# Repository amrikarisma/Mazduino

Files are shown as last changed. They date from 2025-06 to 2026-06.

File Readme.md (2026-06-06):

# Mazduino
*Mazduino ECU* is built on **STM32** MCU, compatible with **rusEFI**-based firmware — including official **rusEFI**, **epicEFI**, **FomeEFI**, and other rusEFI-based custom firmware. For tuning and configuration, you can use the Tuner Studio software.

## Mazduino ECU Compact
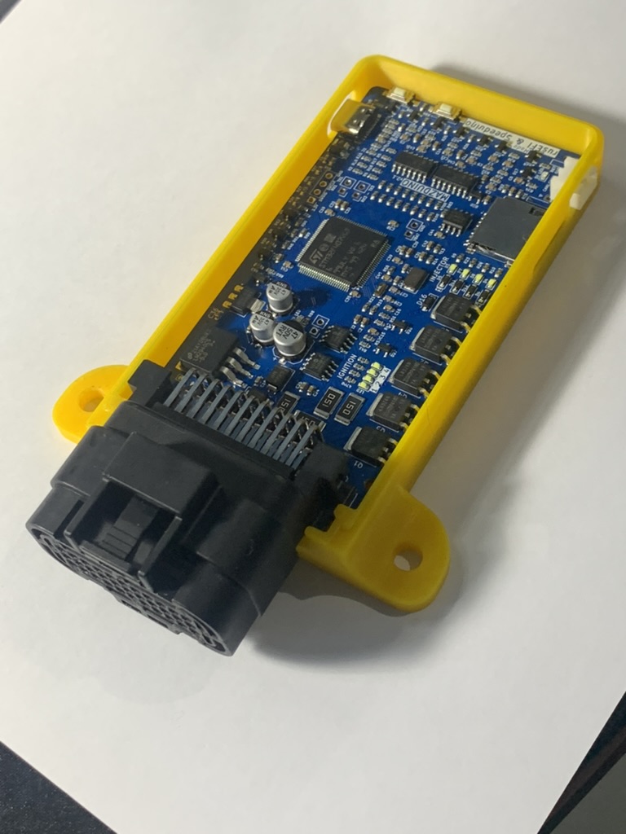
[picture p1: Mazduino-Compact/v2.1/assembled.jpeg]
Assembled Mazduino ECU

A compact and customizable Engine Control Unit (ECU) designed for **4-cylinder engines with full sequential injection and ignition**.

## Mazduino ECU Mini 6Ch
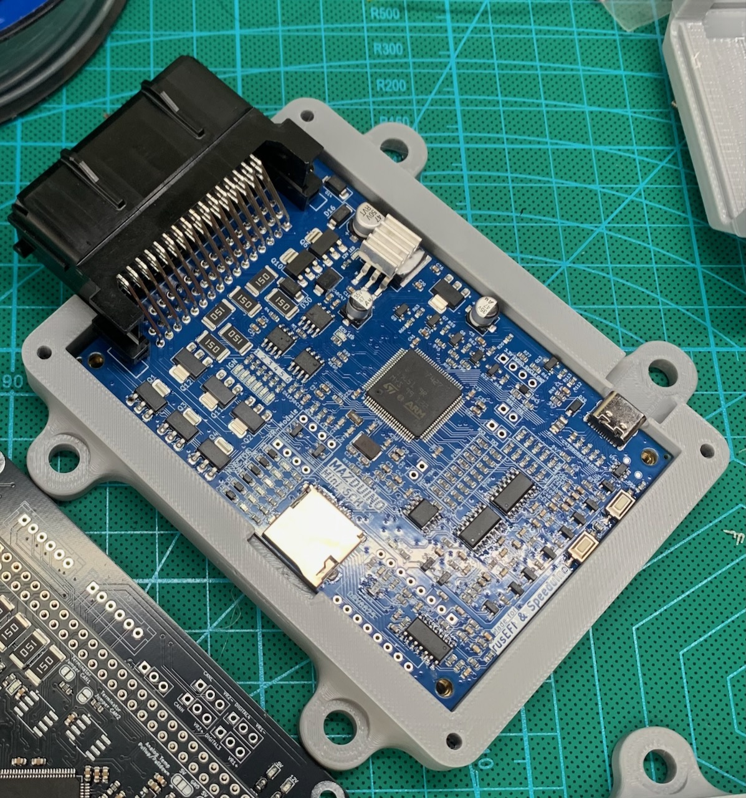
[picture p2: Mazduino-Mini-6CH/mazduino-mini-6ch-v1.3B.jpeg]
Assembled Mazduino ECU

A mini 6-channel version of the Mazduino ECU for **6-cylinder engines with full sequential injection and ignition**.

## Mazduino ECU Lite Edition
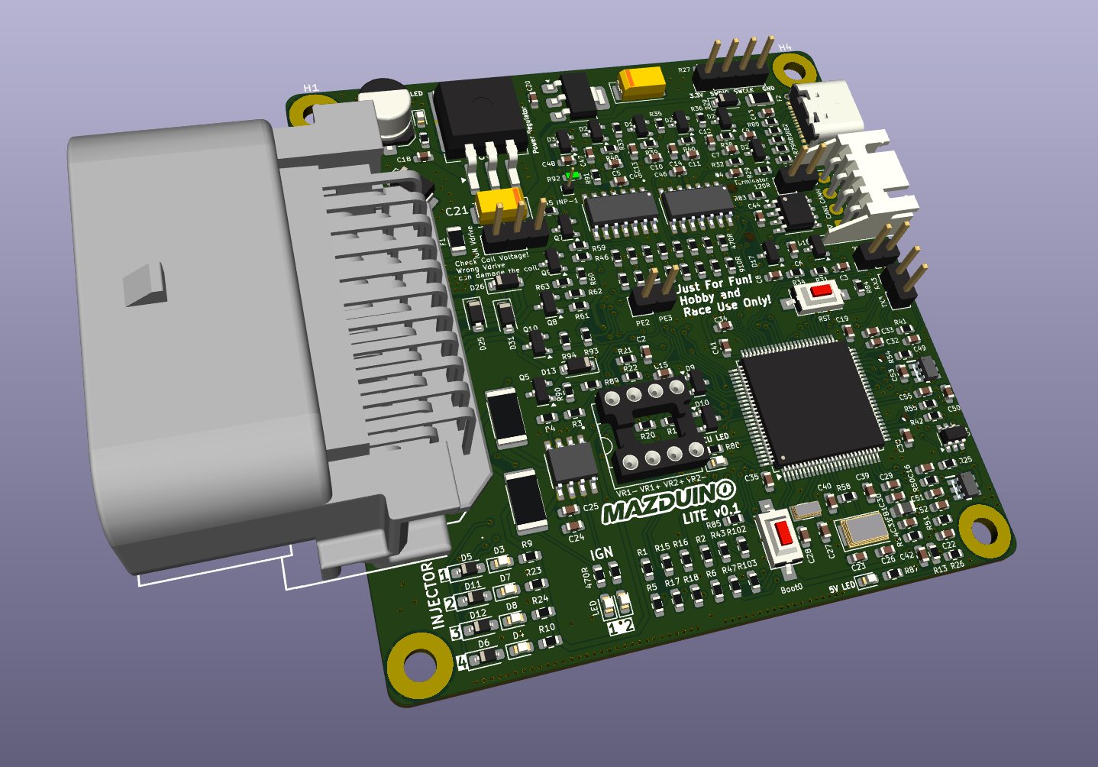
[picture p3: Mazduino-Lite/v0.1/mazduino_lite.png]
Mazduino Lite Edition

A lightweight and compact ECU designed for **4-cylinder engines with full sequential injection and wasted spark ignition**.

## Mazduino Display
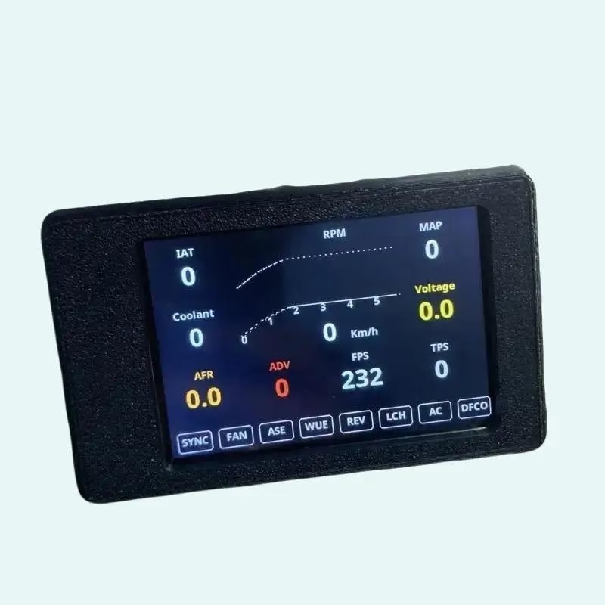
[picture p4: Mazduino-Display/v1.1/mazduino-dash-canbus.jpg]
Mazduino Display

A dedicated dashboard ECU display module that shows real-time vehicle data retrieved from the main ECU.

## Mazduino WBO (Wideband Oxygen Sensor Controller)
Mazduino WBO
A wideband oxygen sensor controller that communicates with the ECU via CAN bus for accurate air-fuel ratio monitoring. Supports LSU 4.2, LSU 4.9, and LSU 4.9 Adv sensors with easy manual assembly design.

*Documentation for all variants will be updated as soon as possible.*

## Links
### Mazduino
- **Official Website**: https://www.mazduino.com
- **Documentation & WIKI**: https://wiki.mazduino.com

### Firmware & Software
- **rusEFI**: https://rusefi.com/
- **Tuner Studio**: https://www.tunerstudio.com/index.php/tuner-studio

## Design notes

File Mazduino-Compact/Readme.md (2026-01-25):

# Mazduino Compact
Assembled Mazduino ECU

Mazduino Compact is compatible with firmware from rusEFI and can also be used with Speeduino.  
For tuning and configuration, you can use the Tuner Studio software.

## Downloads

### Latest Version (v2.3)
- [Download Schematic (PDF)](https://github.com/amrikarisma/Mazduino/blob/main/Mazduino-Compact/v2.3/schematic.pdf)
- [Interactive BOM v2.3](https://www.mazduino.com/ibom/compact-2-3-ibom.html)

### Other Versions
- [Interactive BOM v2.2](https://www.mazduino.com/ibom/compact-2-2-ibom.html)
- [Interactive BOM v2.0](https://www.mazduino.com/ibom/compact-2-0-ibom.html)
- [Interactive BOM v1.3](https://www.mazduino.com/ibom/compact-1-3-ibom.html)
*Interactive BOM for other versions will be available soon*

## Changelog

### v1.0
- Initial testing

### v1.1
- Fixed USB-C to USB-C connection: rerouted 5.1k resistor to CC1 & CC2  
- Corrected silkscreen typo  

### v1.2
- Added low-current output for main relay  
- Added spare analog input  
- Added jumper footprint  

### v2.0
- Replaced connector with a 33-pin Yamaha automotive connector  
- Changed 12V capacitor size from 5x5 to 6x5  

### v2.1
- Added one high-current low-side MOSFET for boost/VVT/Idle2 control  
- Added direct knock sensor support using an op-amp IC  
- Supported two types of CAN bus transceivers: MCP2551 or TJA1051T/3  
- Added a dedicated connector for CAN bus communication  
- Added a pin header footprint for VBAT, allowing real-time clock backup with a 3.3V battery

### v2.2
- Added high-side MOSFET for 12V switching control (alternator and other components requiring 12V switching)  

### v2.3
- Fixed MCU mapping for 12V battery input and knock sensor input  
- Optimized component selection and PCB layout for improved reliability and manufacturing efficiency  
- Added JST connector footprint for usb connector options  
- Added CR1220 battery holder footprint for real-time clock backup power

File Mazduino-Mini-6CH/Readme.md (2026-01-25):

# Mazduino Mini 6Ch

Mazduino Mini 6Ch is compatible with firmware from rusEFI and can also be used with Speeduino.  
For tuning and configuration, you can use the Tuner Studio software.

## Preview
<table>
  <tr>
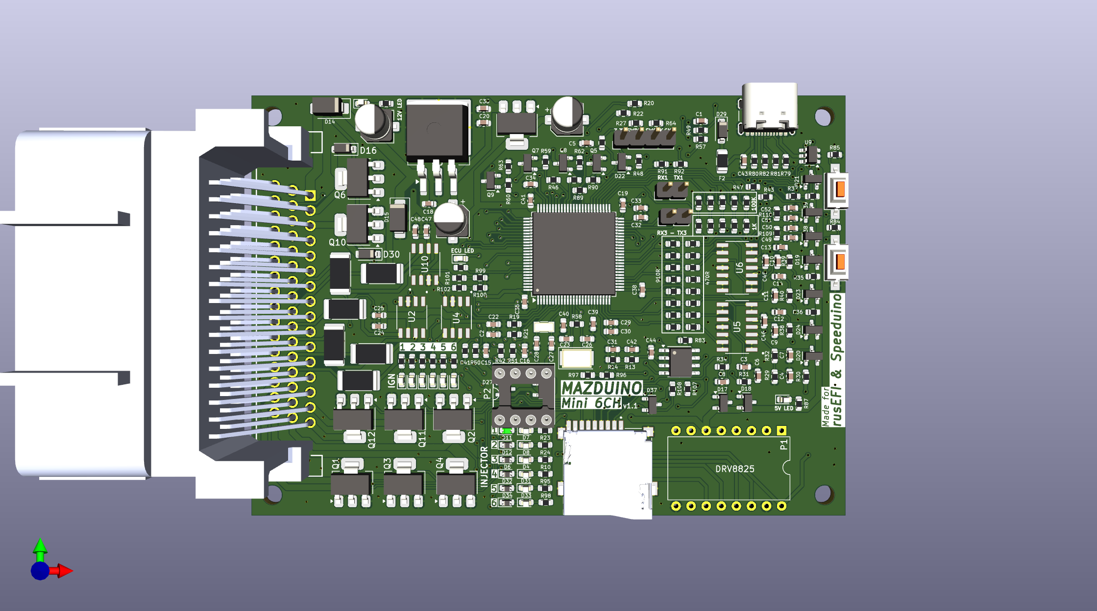
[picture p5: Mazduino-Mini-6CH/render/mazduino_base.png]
3D Render top
    <td></td>
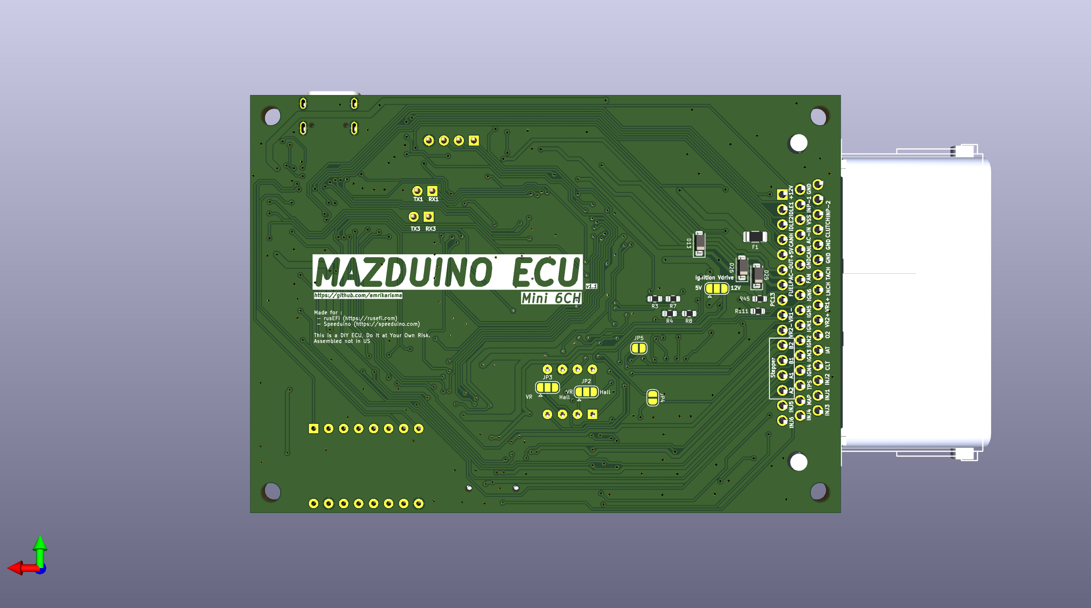
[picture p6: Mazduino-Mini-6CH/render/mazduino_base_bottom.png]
3D Render bottom
    <td></td>
  </tr>
  <tr>
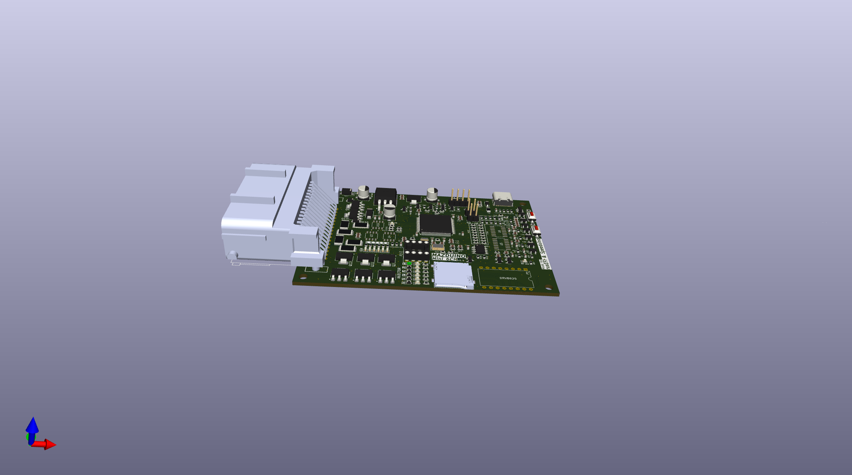
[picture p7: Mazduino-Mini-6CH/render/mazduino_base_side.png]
3D Render side
    <td></td>
    <td>Assembled Mazduino ECU</td>
  </tr>
</table>

## Features
- Processor/MCU: STM32F407
- 6 Channel Coil outputs for Smart Coil (For dumb coil, please add external IGBT)
- 6 Channel Injector outputs
- 2 High Current Outputs (Idle/Boost/VVT)
- Tachometer Output
- Fuel Pump Low Current Output
- FAN Low Current Output
- AC Compressor Low Current Output
- CKP Trigger Input (Hall/Optical/VR)
- CMP Trigger Input (Hall/Optical/VR)
- Supports VR-Conditioner Module (DIP 8)
- Supports Stepper Module (DRV8825)
- External MAP Sensor Analog Input
- TPS Sensor Analog Input
- IAT Sensor Analog Input
- ECT/CLT Sensor Analog Input
- O2 Sensor Analog Input
- Spare Analog Input 1 (Can be used for Fuel Pressure Sensor or others)
- Spare Analog Input 2 (Can be used for Oil Pressure Sensor or others)
- AC Switch Digital Input/GND signal
- Launch Control Input
- Clutch Input
- VSS Input
- Supports Micro SD Card for data logging via SPI
- Supports CANbus communication with MCP2551 IC
- Automotive 48-pin Yamaha ECU Connector

## Downloads

### Latest Version (v1.4)
- [Download Schematic (PDF)](https://github.com/amrikarisma/Mazduino/blob/main/Mazduino-Mini-6CH/v1.4/Schematics.pdf)
- [Interactive BOM v1.4](https://www.mazduino.com/ibom/mini6ch-1-4-ibom.html)

### Other Versions
- [Interactive BOM v1.3](https://www.mazduino.com/ibom/mini6ch-1-3-ibom.html)
- [Interactive BOM v1.2](https://www.mazduino.com/ibom/mini6ch-1-2-ibom.html)
  
## Changelog

### v1.0
- Initial Release

### v1.1
- Fix USB D+ and D-
- Add 2 Spare analog inputs
- Change AC Switch from Analog Input to Digital Pin (GND signal)

### v1.2
- Replace footprint Capacitor for Input Regulator 5V from 5x5 to 8x6
- Add low current output for Main relay control
- Fix DRV8825 schema for rusEFI

### v1.3
- Added ETB support
- Added Knock sensor support

### v1.4 (latest)
- Added spare inputs to support TPS1, TPS2, PPS1, PPS2
- Added support for ETB1 and ETB2
- Motor driver uses 2x TLE9201SG ICs (can be used for Idle Stepper Motor when not used for ETB)
- Removed DRV8825 module support

---

*This documentation will be updated as soon as possible... please wait.*

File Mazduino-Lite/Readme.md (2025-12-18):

# Mazduino Lite Edition

Mazduino Lite Edition is a compact ECU designed for **4-cylinder engines with wasted spark ignition or 1-2 cylinder motorcycles with individual ignition control**. All configurations support full sequential injection. This lightweight version provides essential engine control features in a smaller form factor.

Mazduino Lite is compatible with firmware from rusEFI and can also be used with Speeduino.  
For tuning and configuration, you can use the Tuner Studio software.

## Specifications
- **Board Size**: 72mm x 74.7mm
- **Connector**: 33-pin Automotive Connector
- **Target Application**: 
  - 4-cylinder engines with full sequential injection and wasted spark ignition
  - 1-cylinder motorcycles with sequential injection and individual ignition control
  - 2-cylinder motorcycles with sequential injection and individual ignition control (Smart Coil/IGBT)

## Preview
### v0.1
<table>
  <tr>
    <td>Mazduino Lite v0.1</td>
    <td></td>
  </tr>
</table>

### v0.2
<table>
  <tr>
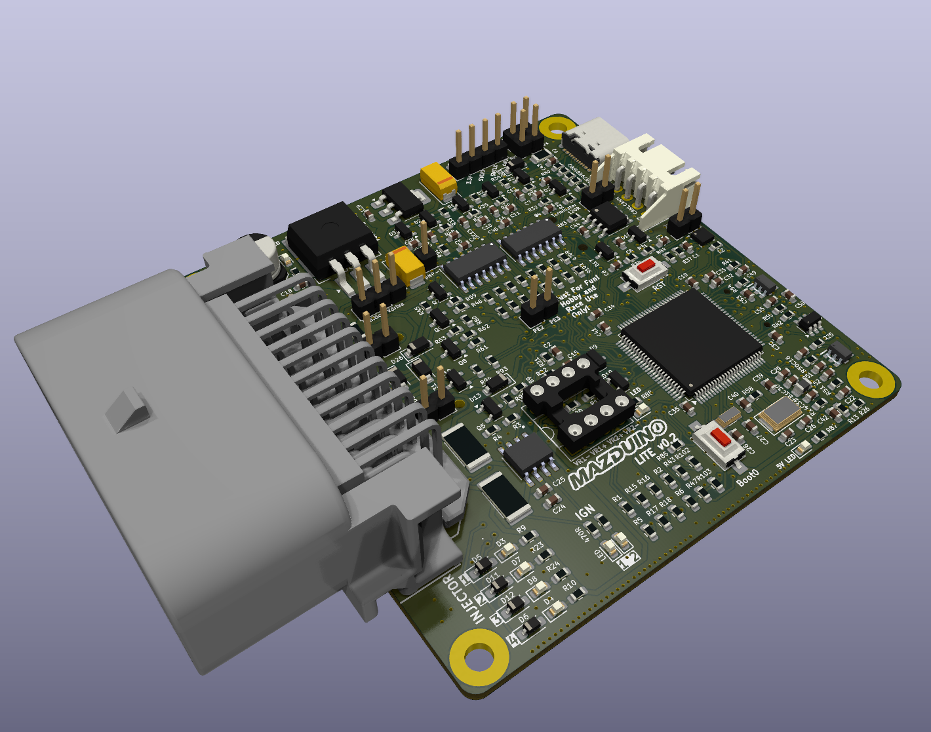
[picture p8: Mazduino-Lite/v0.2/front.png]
Mazduino Lite v0.2 Top
    <td></td>
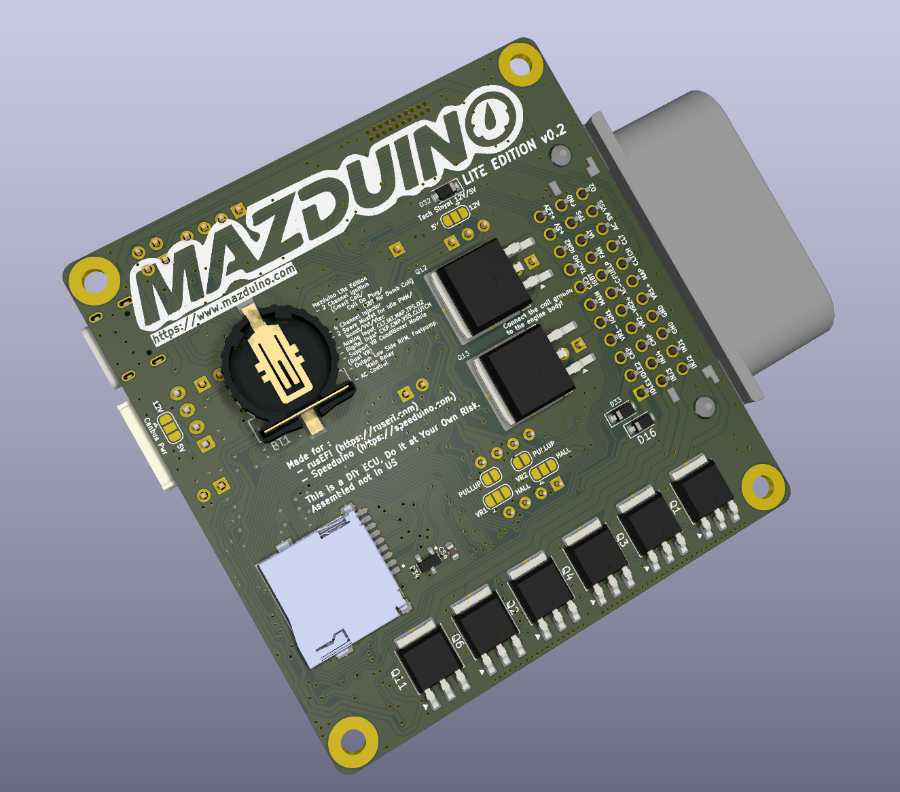
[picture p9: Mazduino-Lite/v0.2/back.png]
Mazduino Lite v0.2 Bottom
    <td></td>
  </tr>
</table>

## Features
- **Processor/MCU**: STM32F407
- **2 Channel Ignition** - Wasted Spark (Smart Coil/Coil On Plug/IGBT for Dumb Coil)
- **4 Channel Injector** outputs - Full Sequential Injection
- **2 Spare MOSFET** for Idle PWM/Boost/VVT/VTEC control
- **Analog Inputs**: CLT, IAT, MAP, TPS, O2 sensors
- **Internal Baro Pressure Sensor**: Built-in barometric pressure sensor (v0.2+)
- **Digital Inputs**: CKP, CMP, VSS, Clutch
- **VR Conditioner Module Support** (Dual VR)
- **Low Side Outputs**: RPM, FAN, Fuel Pump, Main Relay, AC Compressor
- **Micro SD Card Support** for data logging via SPI
- **CANbus Communication** support
- **Compact Design** - Smaller footprint for space-constrained applications

## Downloads

### Latest Version (v0.2)
- [Download Schematic (PDF)](https://github.com/amrikarisma/Mazduino/blob/main/Mazduino-Lite/v0.2/Schematics.pdf)
- [Interactive BOM v0.2](https://www.mazduino.com/ibom/lite-0-2-ibom.html)

### Other Versions
- [Download Schematic v0.1 (PDF)](https://github.com/amrikarisma/Mazduino/blob/main/Mazduino-Lite/v0.1/Schematics.pdf)
- [Interactive BOM v0.1](https://www.mazduino.com/ibom/lite-0-1-ibom.html)

## Changelog

### v0.2 (Latest - Important IGBT Revision)
- **Critical IGBT Fix**: Resolved design error in v0.1 that could prevent IGBT functionality
- **Footprint Change**: Updated IGBT footprint from Dpak 252 to d2pak 262 (commonly used for IGBT)
- **Added Internal Baro Pressure Sensor**: Built-in barometric pressure sensor for improved engine management
- Design validation and schematic corrections

### v0.1 (Initial Release)
- Initial design and layout
- Compact 72mm x 74.7mm form factor
- 33-pin automotive connector
- 4-cylinder full sequential injection with wasted spark ignition
- 2-channel ignition and 4-channel injection
- Essential analog and digital inputs
- VR conditioner support
- CAN bus and SD card support
- ⚠️ **Note**: Contains IGBT design issue for dumb coils (resolved in v0.2)
- ✅ **Still usable**: Works perfectly with Coil on Plug (CoP) or Smart Coil configurations

---

*This documentation will be updated as soon as possible... please wait.*

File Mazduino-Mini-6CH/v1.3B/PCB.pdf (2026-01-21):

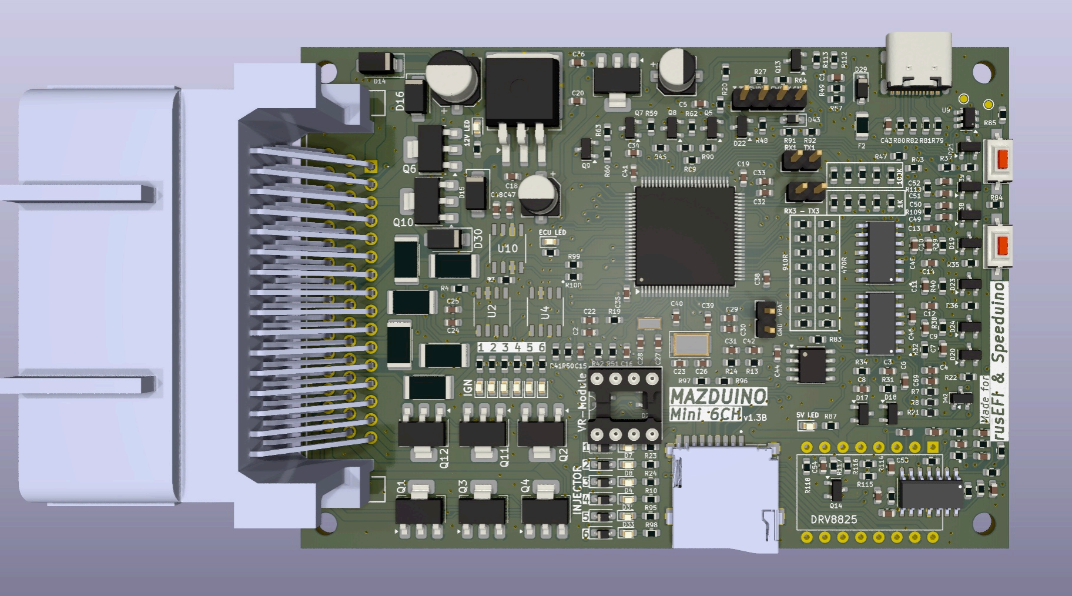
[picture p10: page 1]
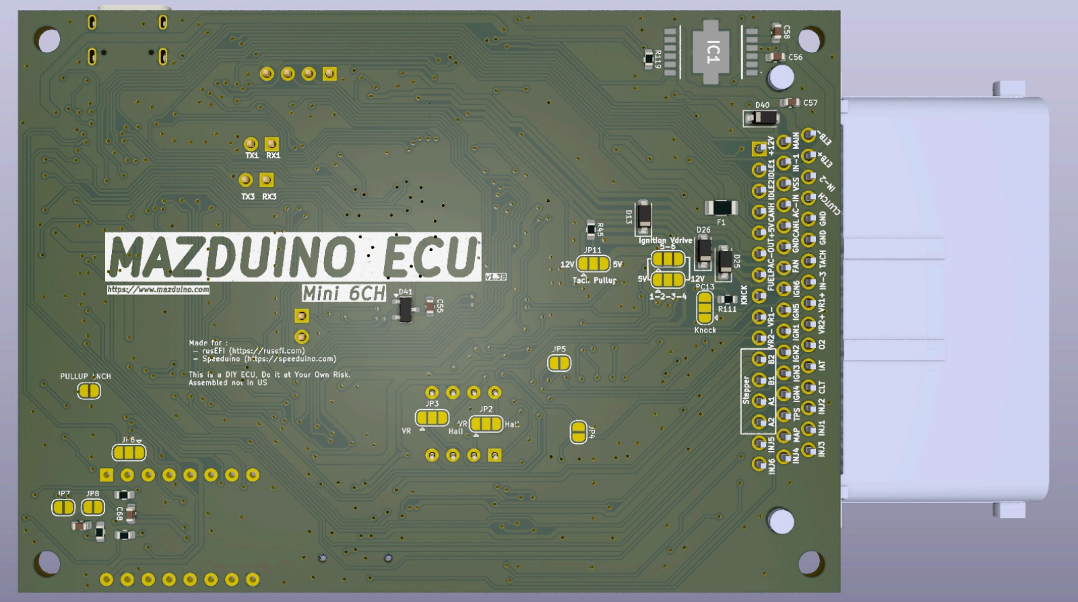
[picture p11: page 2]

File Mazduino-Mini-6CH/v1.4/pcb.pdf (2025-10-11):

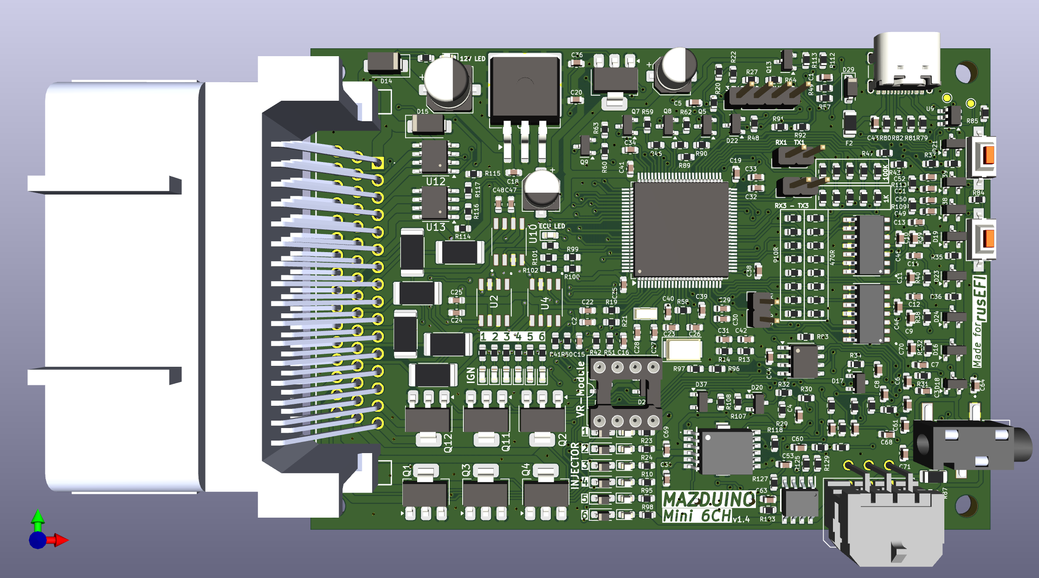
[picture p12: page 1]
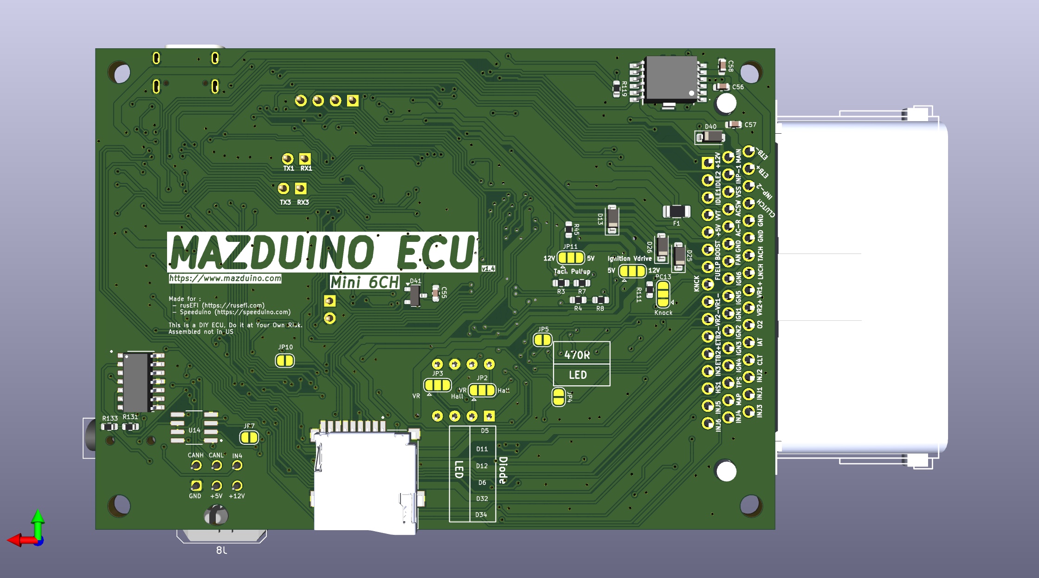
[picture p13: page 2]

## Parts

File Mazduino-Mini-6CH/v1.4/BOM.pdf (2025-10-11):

Reference | Value | Footprint | Qty
C1,C2,C3,C7,C9,C10,C11,C16,C18,C19,C20,C24,C30,C35,C36,C38,C39,C40,C41,C42,C44,C45,C46,C47,C49,C51,C55,C61,C64,C68 100nF | | Capacitor_SMD:C_0603_1608Metric | 30
C4,C22,C25,C29,C31,C33,C48 | 1uF | Capacitor_SMD:C_0603_1608Metric | 7
C5,C6,C12,C13,C14,C50,C52,C70 | 220nF | Capacitor_SMD:C_0603_1608Metric | 8
C8 | 470pF | Capacitor_SMD:C_0603_1608Metric | 1
C15,C53,C54,C57,C58,C59,C63 | 10nF | Capacitor_SMD:C_0603_1608Metric | 7
C17 | 10uF | Capacitor_SMD:CP_Elec_6.3x5.4 | 1
C21 | 47uF | Capacitor_SMD:CP_Elec_5x5.3 | 1
C23,C26 | 12pF | Capacitor_SMD:C_0603_1608Metric | 2
C27,C28 | 20pF | Capacitor_SMD:C_0603_1608Metric | 2
C32,C34 | 2.2uF | Capacitor_SMD:C_0603_1608Metric | 2
C37 | 47uF | Capacitor_SMD:CP_Elec_5x5.4 | 1
C43,C56,C69,C71 | 10uF | Capacitor_SMD:C_0603_1608Metric | 4
C60 | 3.3nF | Capacitor_SMD:C_0603_1608Metric | 1
C62 | 680pF | Capacitor_SMD:C_0603_1608Metric | 1
C65 | 330pF | Capacitor_SMD:C_0603_1608Metric | 1
C66 | 47pF | Capacitor_SMD:C_0603_1608Metric | 1
D1,D2,D3,D4,D7,D8,D9,D10,D31,D33,D35,D36 | LED | LED_SMD:LED_0603_1608Metric | 12
D5,D6,D11,D12,D32,D34 | 1N4148WS | Diode_SMD:D_SOD-323_HandSoldering | 6
D13,D25,D26,D29,D40 | 1N5819W | Diode_SMD:D_SOD-123 | 5
D14 | SS14 | Diode_SMD:D_SMA | 1
D15 | D_TVS | Diode_SMD:D_SMA | 1
D16,D17,D18,D19,D20,D21,D22,D23,D24,D27,D28,D37,D38,D39 | BAT54S | Package_TO_SOT_SMD:SOT-23 | 14
D41 | BAT54C | Package_TO_SOT_SMD:SOT-23 | 1
F1,F3 | 0.5A | Fuse:Fuse_1206_3216Metric | 2
F2 | 1206 | Fuse:Fuse_1206_3216Metric | 1
IC1,IC2 | TLE9201SG | TLE9201SG | 2
IC3 | BTS4175SGA | SOIC127P600X175-8N | 1
J1,J6,J7 | Conn_01x02 | Connector_PinHeader_2.54mm:PinHeader_1x02_P2.54mm_Vertical | 3
J2 | STLink | Connector_PinHeader_2.54mm:PinHeader_1x04_P2.54mm_Vertical | 1
J3 | USB_C_Receptacle_USB2.0 | Connector_USB:USB_C_Receptacle_GCT_USB4105-xx-A_16P_TopMnt_Horizontal | 1
J4 | PJ-320B | PJ-320B:BOOMELE_PJ-320B | 1
J5 | MSD-1-A | MSD_1_A:CUI_MSD-1-A | 1
J8 | Conn_02x02_Top_Bottom | Connector_Molex:Molex_Micro-Fit_3.0_43045-0600_2x03_P3.00mm_Horizontal | 1
J9 | S48B-ZROK-2A-R | S48BZROK2AR | 1
JP1 | Ignition Voltage | Jumper:SolderJumper-3_P1.3mm_Open_RoundedPad1.0x1.5mm | 1
JP2,JP3 | HALL_VR | Jumper:SolderJumper-3_P1.3mm_Open_RoundedPad1.0x1.5mm | 2
JP4,JP5 | PULLUP | Jumper:SolderJumper-2_P1.3mm_Open_RoundedPad1.0x1.5mm | 2
JP10 | VRef | Jumper:SolderJumper-2_P1.3mm_Open_RoundedPad1.0x1.5mm | 1
LED1,LED2,LED3 | RED | LED_SMD:LED_0603_1608Metric | 3
P2 | Dual VR C | Package_DIP:DIP-8_W7.62mm_Socket | 1
Q1,Q2,Q3,Q4,Q11,Q12 | Q_NMOS_GDS | Package_TO_SOT_SMD:SOT-223-3_TabPin2 | 6
Q5,Q7,Q8,Q9,Q13 | AO3400A | Package_TO_SOT_SMD:SOT-23 | 5
R1,R2,R15,R16,R43,R91,R93,R96,R114,R115 | 100k | Resistor_SMD:R_0603_1608Metric | 10
R3,R4,R19,R20,R27,R29,R33,R45,R59,R62,R63,R64,R84,R85,R90,R99,R100,R113,R118,R119,R125,R127,R129 10K | | Resistor_SMD:R_0603_1608Metric | 23
R5,R6,R17,R18,R37,R47,R49,R92,R94,R97,R107,R116,R117 | 1k | Resistor_SMD:R_0603_1608Metric | 13
R7,R8,R21,R22,R101,R102 | 0R | Resistor_SMD:R_0603_1608Metric | 6
R9,R10,R23,R24,R95,R98 | 2.4k | Resistor_SMD:R_0603_1608Metric | 6
R11,R12,R13,R25,R26,R28,R31,R32,R34,R38,R39,R40,R44,R48,R50,R51,R65,R66,R71,R72,R73,R74,R87,R88,R103,R104,R109,R110,R131,R132 470R | | Resistor_SMD:R_0603_1608Metric | 30
R14,R67,R68,R69,R70,R75,R76,R77,R78,R133 | 910R | Resistor_SMD:R_0603_1608Metric | 10
R30 | 82K | Resistor_SMD:R_0603_1608Metric | 1
R35,R36 | 2.49k | Resistor_SMD:R_0603_1608Metric | 2
R41,R42,R56,R86,R108 | 2k7 | Resistor_SMD:R_0603_1608Metric | 5
R46,R60,R61,R89,R112 | 100R | Resistor_SMD:R_0603_1608Metric | 5
R52,R53,R54,R55,R105,R106 | 15R | Resistor_SMD:R_2512_6332Metric | 6
R57 | 220R | Resistor_SMD:R_0603_1608Metric | 1
R58 | 1M | Resistor_SMD:R_0603_1608Metric | 1
R79,R80 | 5.1K | Resistor_SMD:R_0603_1608Metric | 2
R81,R82,R111 | 22R | Resistor_SMD:R_0603_1608Metric | 3
R83,R123 | 4.7K | Resistor_SMD:R_0603_1608Metric | 2
R120,R121,R130 | 33K | Resistor_SMD:R_0603_1608Metric | 3
R122,R128 | 100K | Resistor_SMD:R_0603_1608Metric | 2
R124 | 470K | Resistor_SMD:R_0603_1608Metric | 1
R126 | 12K | Resistor_SMD:R_0603_1608Metric | 1
R134,R136 | 470R | Resistor_SMD:R_0603_1608Metric | 2
R135,R137 | 910R | Resistor_SMD:R_0603_1608Metric | 2
SW1,SW2 | SW_Push | Button_Switch_SMD:SW_SPST_CK_RS282G05A3 | 2
TP1,TP2 | TestPoint | TestPoint:TestPoint_Pad_D1.0mm | 2
U1 | STM32F407VGTx | Package_QFP:LQFP-100_14x14mm_P0.5mm | 1
U2,U4,U10 | TC4424A | TC4424AVOA:SOIC127P599X175-8N | 3
U3 | AMS1117-3.3 | Package_TO_SOT_SMD:SOT-223-3_TabPin2 | 1
U5,U6,U11 | MCP6004 | MCP6004T_I_SL:SOIC127P600X175-14N | 3
U7 | MCP2551-I-SN | Package_SO:SOIC-8_3.9x4.9mm_P1.27mm | 1
U8 | LM2940S-5.0 | Package_TO_SOT_SMD:TO-263-3_TabPin2 | 1
U9 | USBLC6-2SC6 | Package_TO_SOT_SMD:SOT-23-6 | 1
U12,U13 | VNLD5090 | Package_SO:SO-8_3.9x4.9mm_P1.27mm | 2
U14 | MCP6002-xSN | MCP6002T_I_SN:SOIC127P600X175-8N | 1
Y1 | 8Mhz | Crystal:Crystal_SMD_5032-2Pin_5.0x3.2mm | 1
Y2 | 32.768KHz | Crystal:Crystal_SMD_3215-2Pin_3.2x1.5mm | 1

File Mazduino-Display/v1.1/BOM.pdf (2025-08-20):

## BOM Mazduino Display Canbus www.mazduino.com

Qty | Reference | Value | Footprint
2 | C1,C13 | 220uF | Capacitor_SMD:C_Elec_8x10.2
1 | C2 | 100nF | Capacitor_SMD:C_0805_2012Metric
2 | C3,C12 | 22uF | Capacitor_SMD:CP_Elec_5x5.4
5 | C4,C6,C8,C10,C11 | 0.1uF/100nF | Capacitor_SMD:C_0805_2012Metric
2 | C5,C7 | 22uF | Capacitor_SMD:C_0805_2012Metric
1 | C9 | 100nF | Capacitor_SMD:C_0603_1608Metric
1 | D2 | SS14 | Diode_SMD:D_SMA
1 | D3 | SP0503BAHT | Package_TO_SOT_SMD:SOT-143
2 | D4,D5 | SS36 | Diode_SMD:D_SMA
1 | J1 | Conn_01x02_Pin | Connector_JST:JST_XH_B2B-XH-A_1x02_P2.50mm_Vertical
1 | J2 | JST 4P | Connector_JST:JST_XH_B4B-XH-A_1x04_P2.50mm_Vertical
1 | J3 | TFT SPI | Connector_PinSocket_2.54mm:PinSocket_1x14_P2.54mm_Vertical
1 | J5 | USB_C_Receptacle_USB2.0 | Connector_USB:USB_C_Receptacle_GCT_USB4105-xx-A_16P_TopMnt_Horizontal
2 | J6,J7 | TFT SD | Connector_PinSocket_2.54mm:PinSocket_1x04_P2.54mm_Vertical
1 | JP1 | Jumper_2_Open | Connector_PinHeader_2.54mm:PinHeader_1x02_P2.54mm_Vertical
1 | L1 | 33uH | Inductor_SMD:L_10.4x10.4_H4.8
2 | LED1,LED4 | LED | LED_SMD:LED_0805_2012Metric
1 | LED2 | BLUE | LED_SMD:LED_0805_2012Metric
1 | LED3 | GREEN | LED_SMD:LED_0805_2012Metric
2 | Q1,Q2 | SS8050 | Package_TO_SOT_SMD:SOT-23
4 | R1,R6,R9,R10 | 10K | Resistor_SMD:R_0805_2012Metric
1 | R2 | 22.1K | Resistor_SMD:R_0805_2012Metric
3 | R3,R17,R18 | 470R | Resistor_SMD:R_0805_2012Metric
1 | R4 | 47.5K | Resistor_SMD:R_0805_2012Metric
1 | R5 | 2K | Resistor_SMD:R_0805_2012Metric
2 | R7,R8 | 0R | Resistor_SMD:R_0805_2012Metric
1 | R11 | 4.7K | Resistor_SMD:R_0603_1608Metric
2 | R12,R13 | 5k1 | Resistor_SMD:R_0805_2012Metric
1 | R14 | 120R | Resistor_SMD:R_0805_2012Metric
2 | R15,R16 | 100R | Resistor_SMD:R_0805_2012Metric
1 | R19 | 4.7K | Resistor_SMD:R_0805_2012Metric
2 | SW1,SW2 | SW_Push | Button_Switch_THT:SW_PUSH_6mm
1 | U1 | AMS1117-3.3 | Package_TO_SOT_SMD:SOT-223-3_TabPin2
1 | U3 | ESP32-WROOM-32D | RF_Module:ESP32-WROOM-32D
1 | U4 | CP2102N-Axx-xQFN28 | Package_DFN_QFN:QFN-28-1EP_5x5mm_P0.5mm_EP3.35x3.35mm
1 | U5 | MCP2551-I-SN | Package_SO:SOIC-8_3.9x4.9mm_P1.27mm
1 | U6 | ESP32-DevKitC | PCM_Espressif:ESP32-DevKitC
1 | U7 | LM2596S-5 | Package_TO_SOT_SMD:TO-263-5_TabPin3

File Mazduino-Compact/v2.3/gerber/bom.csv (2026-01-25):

Designator | Footprint | Quantity | Value | LCSC Part #
BT1 | CR1220-2 | 1 | Battery_Cell
C1, C10, C11, C18, C2, C24, C3, C30, C36, C4, C42, C43, C44, C45, C46, C47, C54, C56, C9 | 0603 | 19 | 100nF
C12 | 0603 | 1 | 220nF | C21120
C13, C14, C48, C5, C6, C7 | 0603 | 6 | 220nF
C15, C19, C35, C38, C39, C40, C41 | 0603 | 7 | 100nF | C14663
C16, C53, C55 | 0603 | 3 | 10nF
C17 | CP_Elec_6.3x5.4 | 1 | 10uF
C21 | CP_Elec_5x5.3 | 1 | 47uF
C22 | 0603 | 1 | 1uF | C15849
C23 | 0603 | 1 | 12pF | C38523
C25, C29, C31, C33, C57 | 0603 | 5 | 1uF
C26 | 0603 | 1 | 12pF
C27 | 0603 | 1 | 20pF | C1648
C28 | 0603 | 1 | 20pF
C32 | 0603 | 1 | 2.2uF | C23630
C34 | 0603 | 1 | 2.2uF
C37 | CP_Elec_5x5.4 | 1 | 47uF
C49 | 0603 | 1 | 3.3nF
C50 | 0603 | 1 | 680pF
C51 | 0603 | 1 | 330pF
C52 | 0603 | 1 | 47pF
C8 | 0603 | 1 | 470pF | C1620
D1, D2, D3, D4, D7, D8, D9 | 0603 | 7 | LED
D10 | 0603 | 1 | LED | C2290
D11 | D_SOD-323_HandSoldering | 1 | 1N4148WS | C2128
D12, D5, D6 | D_SOD-323_HandSoldering | 3 | 1N4148WS
D13, D16, D25, D26, D29, D31, D32, D33 | D_SOD-123 | 8 | 1N5819W
D14 | D_SMA | 1 | SS14 | C2480
D15 | D_SMA | 1 | SMBJ40A
D17 | SOT-23 | 1 | BAT54S | C7420333
D18, D19, D20, D21, D22, D23, D24, D27, D28, D30, D35 | SOT-23 | 11 | BAT54S
D34 | SOT-23 | 1 | BAT54C
F1 | 1206 | 1 | 0.5A
F2 | 1206 | 1 | 1206
IC1 | SOIC127P600X175-8N | 1 | BTS4175SGA
J1 | JST_XH_S4B-XH-A-1_1x04_P2.50mm_Horizontal | 1 | Conn_01x04
J10 | JST_GH_SM04B-GHS-TB_1x04-1MP_P1.25mm_Horizontal | 1 | Conn_01x04
J2 | PinHeader_1x04_P2.54mm_Vertical | 1 | STLink
J3 | USB_C_Receptacle_GCT_USB4105-xx-A_16P_TopMnt_Horizontal | 1 | TYPE-C 16PIN 2MD(073) | C2765186
J4 | PinHeader_1x01_P2.54mm_Vertical | 1 | Conn_01x01
J5 | CUI_MSD-1-A | 1 | THD2528-11SD-GF
J6, J7, J8 | PinHeader_1x02_P2.54mm_Vertical | 3 | Conn_01x02
J9 | 15544582 | 1 | 1554458-2
JP1 | SolderJumper-3_P1.3mm_Open_RoundedPad1.0x1.5mm | 1 | Ignition Voltage
LED1 | 0603 | 1 | RED | C2286
LED2, LED3, LED4 | 0603 | 3 | RED | SML-310LTT86
Q1, Q11, Q2, Q3, Q4, Q6 | TO-252-3_TabPin2 | 6 | Q_NMOS_GDS
Q10, Q7, Q8, Q9 | SOT-23 | 4 | AO3400A | C344010
Q5 | SOT-23 | 1 | AO3400A | C20917
R1, R102, R16, R2, R43, R95, R98 | 0603 | 7 | 100k
R10 | 0603 | 1 | 2.4k | C22940
R100, R101, R99 | 0603 | 3 | 33K
R103, R18, R37, R47, R49, R5, R6 | 0603 | 7 | 1k
R104 | 0603 | 1 | 4.7K
R105, R106, R107, R108, R19, R20, R27, R3, R4, R64, R84, R85 | 0603 | 12 | 10K
R109 | 0603 | 1 | 82K
R11, R12, R25, R26, R30, R34, R38, R39, R40, R48, R51, R92 | 0603 | 12 | 470r
R13, R28, R44, R65, R66, R71, R72, R73, R74 | 0603 | 9 | 470
R14 | 0603 | 1 | 910 | C140066
R15 | 0603 | 1 | 100k | C25803
R17 | 0603 | 1 | 1k | C21190
R23, R24, R9 | 0603 | 3 | 2.4k
R29, R35, R36, R91 | 0603 | 4 | 2.49k
R31 | 0603 | 1 | 470R | C23179
R33, R59, R62, R63, R90, R94 | 0603 | 6 | 10k | C25804
R41, R42, R56 | 0603 | 3 | 2k7
R45 | 0603 | 1 | 10k | C21190
R46, R60, R61, R89, R93 | 0603 | 5 | 100R | C22775
R50 | 0603 | 1 | 470R | C22962
R52, R53, R54, R55 | 2512 | 4 | 15R
R57 | 0603 | 1 | 220R
R58 | 0603 | 1 | 1M | C22935
R67, R68, R69, R70, R75, R76, R77, R78 | 0603 | 8 | 910
R7, R87, R88 | 0603 | 3 | 470r | RK73H2ATTD4700F
R79 | 0603 | 1 | 5.1K | C23186
R80 | 0603 | 1 | 5.1K
R81 | 0603 | 1 | 22R | C23345
R82 | 0603 | 1 | 22R
R83 | 0603 | 1 | 4.7K | C23162
R86 | 0603 | 1 | 2k7 | C13167
R96 | 0603 | 1 | 470K
R97 | 0603 | 1 | 12K
SW1 | SW_SPST_CK_RS282G05A3 | 1 | SW_Push | TSA363G25-250B
SW2 | SW_SPST_CK_RS282G05A3 | 1 | SW_Push
U1 | LQFP-100_14x14mm_P0.5mm | 1 | STM32F407VGTx | C12345
U10 | SOIC127P600X175-8N | 1 | MCP6002-xSN
U2, U4 | SOIC127P599X175-8N | 2 | TC4424AVOA | C44150
U3 | SOT-223-3_TabPin2 | 1 | AMS1117-3.3 | C6186
U5, U6 | SOIC127P600X175-14N | 2 | MCP6004
U7 | SOIC-8_3.9x4.9mm_P1.27mm | 1 | MCP2551-I-SN
U8 | TO-263-3_TabPin2 | 1 | LM2940S-5.0
Y1 | Crystal_SMD_5032-2Pin_5.0x3.2mm | 1 | 8Mhz | C115962
Y2 | Crystal_SMD_3215-2Pin_3.2x1.5mm | 1 | 32.768KHz | C32346

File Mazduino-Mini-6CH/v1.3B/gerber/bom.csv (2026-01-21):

Designator | Footprint | Quantity | Value | LCSC Part #
C1, C10, C11, C16, C18, C2, C20, C24, C3, C30, C36, C4, C42, C44, C45, C46, C47, C49, C51, C55, C68, C9 | 0603 | 22 | 100nF
C12, C13, C14, C5, C50, C52, C6, C7 | 0603 | 8 | 220nF
C15, C57, C58, C59 | 0603 | 4 | 10nF
C17 | CP_Elec_6.3x5.4 | 1 | 10uF
C19, C35, C38, C39, C40, C41 | 0603 | 6 | 100nF | C14663
C21 | CP_Elec_5x5.3 | 1 | 47uF
C22, C25, C29, C31, C33, C48, C69 | 0603 | 7 | 1uF
C23, C26 | 0603 | 2 | 18pF | C1647
C27, C28 | 0603 | 2 | 6.8pF | C1679
C32, C34, C53 | 0603 | 3 | 2.2uF
C37 | CP_Elec_5x5.4 | 1 | 47uF
C43, C56 | 0603 | 2 | 10uF
C54 | 0603 | 1 | 22nF
C60, C61 | 0603 | 2 | 3.3nF
C62, C63 | 0603 | 2 | 680pF
C64, C65 | 0603 | 2 | 330pF
C66, C67 | 0603 | 2 | 47pF
C8 | 0603 | 1 | 470pF
D1, D10, D2, D3, D31, D33, D35, D36, D4, D7, D8, D9 | 0603 | 12 | LED
D11, D12, D32, D34, D43, D5, D6 | D_SOD-323_HandSoldering | 7 | 1N4148WS
D13, D25, D26, D29, D40 | D_SOD-123 | 5 | 1N5819W
D14, D16, D30 | D_SMA | 3 | SS14 | C2480
D15 | D_SMA | 1 | D_TVS
D17, D18, D19, D20, D21, D22, D23, D24, D27, D28, D38, D39, D42 | SOT-23 | 13 | BAT54S
D41 | SOT-23 | 1 | BAT54C
F1 | 1206 | 1 | 0.5A
F2 | 1206 | 1 | 1206 | C163133
IC1 | TLE9201SG | 1 | TLE9201SG
J1, J6, J7 | PinHeader_1x02_P2.54mm_Vertical | 3 | Conn_01x02
J2 | PinHeader_1x04_P2.54mm_Vertical | 1 | STLink
J3 | USB_C_Receptacle_GCT_USB4105-xx-A_16P_TopMnt_Horizontal | 1 | USB_C_Receptacle_USB2.0 | C2765186
J5 | CUI_MSD-1-A | 1 | MSD-1-A
J9 | S48BZROK2AR | 1 | S48B-ZROK-2A-R
JP1, JP12 | SolderJumper-3_P1.3mm_Open_RoundedPad1.0x1.5mm | 2 | Ignition Voltage
JP10, JP4, JP5 | SolderJumper-2_P1.3mm_Open_RoundedPad1.0x1.5mm | 3 | PULLUP | DNP
JP2, JP3 | SolderJumper-3_P1.3mm_Open_RoundedPad1.0x1.5mm | 2 | HALL_VR | DNP
LED1, LED2, LED3 | 0603 | 3 | RED | SML-310LTT86
P1 | DRV8825 | 1 | DRV8825
P2 | DIP-8_W7.62mm_Socket | 1 | Dual VR C | DNP
Q1, Q11, Q12, Q2, Q3, Q4 | SOT-223-3_TabPin2 | 6 | Q_NMOS_GDS
Q10, Q6 | SOT-223-3_TabPin2 | 2 | BSP78
Q13, Q5, Q7, Q8, Q9 | SOT-23 | 5 | AO3400A | C344010
Q14 | SOT-23 | 1 | BC817
R1, R122, R123, R128, R129, R15, R16, R2, R43, R91, R93, R96 | 0603 | 12 | 100k
R10, R23, R24, R9, R95, R98 | 0603 | 6 | 2.4k
R100, R19, R20, R27, R3, R33, R4, R64, R7, R84, R85, R99 | 0603 | 12 | 10K
R103, R104, R109, R11, R110, R12, R13, R25, R26, R28, R31, R32, R34, R38, R39, R40, R44, R48, R50, R51, R65, R66, R71, R72, R73, R74 | 0603 | 26 | 470R
R105, R106, R52, R53, R54, R55 | 2512 | 6 | 15R
R111, R81, R82 | 0603 | 3 | 22R
R112, R46, R60, R61, R89 | 0603 | 5 | 100R | C22775
R113, R117, R118, R119, R59, R62, R63, R90 | 0603 | 8 | 10K | C25804
R114, R116 | 0603 | 2 | 68K | C25804
R115 | 0603 | 1 | 5.1R | C25804
R120, R121, R130, R131 | 0603 | 4 | 33K
R124, R125 | 0603 | 2 | 470K
R126, R127 | 0603 | 2 | 12K
R14, R67, R68, R69, R70, R75, R76, R77, R78 | 0603 | 9 | 910R
R17, R18, R37, R47, R49, R5, R6, R92, R94, R97 | 0603 | 10 | 1k
R21 | 0603 | 1 | 0R
R22, R35, R36 | 0603 | 3 | 2.49k
R41, R42, R56 | 0603 | 3 | 2k7
R45 | 0603 | 1 | 10K | C21190
R57 | 0603 | 1 | 220R
R79, R80 | 0603 | 2 | 5.1K
R8 | 0603 | 1 | 82K
R83 | 0603 | 1 | 4.7K
R86 | 0603 | 1 | 2k7 | RK73B1JTTD272J
R87, R88 | 0603 | 2 | 470R | RK73H2ATTD4700F
SW1, SW2 | SW_SPST_CK_RS282G05A3 | 2 | SW_Push | C354943
TP1, TP2 | TestPoint_Pad_D1.0mm | 2 | TestPoint
U1 | LQFP-100_14x14mm_P0.5mm | 1 | STM32F427VGTx | C117815
U10, U2, U4 | SOIC127P599X175-8N | 3 | TC4424A
U11, U5, U6 | SOIC127P600X175-14N | 3 | MCP6004
U3 | SOT-223-3_TabPin2 | 1 | AMS1117-3.3
U7 | SOIC-8_3.9x4.9mm_P1.27mm | 1 | TJA1051T/J/3
U8 | TO-263-3_TabPin2 | 1 | LM2940S-5.0
U9 | SOT-23-6 | 1 | USBLC6-2SC6
Y1 | Crystal_SMD_5032-2Pin_5.0x3.2mm | 1 | 8Mhz | C115962
Y2 | Crystal_SMD_3215-2Pin_3.2x1.5mm | 1 | 32.768KHz | C32346

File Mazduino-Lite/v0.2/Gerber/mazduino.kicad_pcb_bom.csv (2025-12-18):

Designator | Quantity | Value | Footprint | Package | MPN | DNP | Mount_Type | Description | LCSC | LCSC_ext | Digikey Part Number | Manufacturer_Name | URL | Voltage | LCSC Part | Height | Mouser Part Number | Mouser Price/Stock | Manufacturer_Part_Name | PARTREV | STANDARD | MAXIMUM_PACKAGE_HEIGHT | MANUFACTURER | JLCPCB_Part
BT1 | 1 | Battery_Cell | CR1220-2 |  |  |  | smt | Single-cell battery
C1 | 1 | 100n | C_0603_1608Metric |  |  |  | smt |  | C14663 | 0
C10, C11, C15, C18, C20, C24, C3, C4, C47, C9 | 10 | 100nF | C_0603_1608Metric |  | FA18X8R1E104KNU06 |  | smt |  |  |  | 445-180563-1-ND | TDK | https://www.digikey.com.au/product-detail/en/tdk-corporation/FA18X8R1E104KNU06/445-180563-1-ND/9560689 | 50v
C12, C13, C14, C48, C5, C6, C7 | 7 | 220nF | C_0603_1608Metric |  | FA18X8R1E224KRU06 |  | smt |  | C21120 |  | 445-180564-1-ND | TDK | https://www.digikey.com.au/product-detail/en/tdk-corporation/FA18X8R1E224KRU06/445-180564-1-ND/9560690
C16, C22, C49, C50, C51, C52, C53, C55 | 8 | 1nF | C_0603_1608Metric |  |  |  | smt |  | C1588
C17 | 1 | 10uF | CP_Elec_6.3x5.4 |  | EEU-FC1H100L |  | smt |  |  |  | P10316-ND | Panasonic | https://www.digikey.com.au/product-detail/en/panasonic-electronic-components/EEU-FC1H100L/P10316-ND/266325 | 50v
C19, C35, C38, C39, C40, C41 | 6 | 100nF | C_0603_1608Metric |  | CC0603KRX7R9BB104 |  | smt |  |  |  |  |  |  |  | C14663
C2 | 1 | 10nF | C_0603_1608Metric |  | FA18X7R1H103KNU06 |  | smt |  |  |  | 445-174244-1-ND | TDK | https://www.digikey.com.au/product-detail/en/tdk-corporation/FA18X7R1H103KNU06/445-174244-1-ND/5865002
C21 | 1 | 47uF | CP_EIA-6032-28_Kemet-C |  | EEU-FC1H470B |  | smt |  |  |  | P19658CT-ND | Panasonic
C23, C26 | 2 | 33pF | C_0603_1608Metric |  |  |  | smt | Unpolarized capacitor | C1663
C25 | 1 | 1uF | C_0603_1608Metric |  | FA18X7R1E105KRU06 |  | smt |  |  |  | 445-180543-1-ND | TDK | https://www.digikey.com.au/product-detail/en/tdk-corporation/FA18X7R1E105KRU06/445-180543-1-ND/9560669
C27, C28 | 2 | 20pF | C_0603_1608Metric |  |  |  | smt | Unpolarized capacitor | C1648
C29, C31, C33 | 3 | 1uF | C_0603_1608Metric |  |  |  | smt | Unpolarized capacitor
C30, C42, C43, C44, C45, C46, C54 | 7 | 100nF | C_0603_1608Metric |  |  |  | smt | Unpolarized capacitor
C32, C34 | 2 | 2.2uF | C_0603_1608Metric |  |  |  | smt | Unpolarized capacitor | C23630
C37 | 1 | 47uF | CP_EIA-6032-28_Kemet-C |  |  |  | smt | Polarized capacitor
C8 | 1 | 470pF | C_0603_1608Metric |  |  |  | smt |  | C1620
D1, D2, D3, D4, D7, D8 | 6 | LED | LED_0603_1608Metric |  | 151031SS04000 |  | smt |  |  |  | 732-5005-ND | Wurth | https://www.digikey.com.au/product-detail/en/w%C3%BCrth-elektronik/151031SS04000/732-5005-ND/4489979
D10, D17, D18, D19, D20, D22, D23, D24, D30, D9 | 10 | BAT54S | SOT-23 |  |  |  | smt | Dual Schottky diode, anode/cathode/center | C7420333
D11, D12, D5, D6 | 4 | 1N4148WS | D_SOD-323_HandSoldering |  | 1N4148WS |  | smt |  | C2128 |  | 1N4148WS | onsemi | [D11,D12,D5]https://www.digikey.com.au/product-detail/en/vishay-general-semiconductor-diodes-division/1N914TAP/1N914TAPGICT-ND/8564478; [D6]https://www.digikey.com/en/products/detail/onsemi/1N4148WT/1954014
D13, D16, D25, D26, D29, D31, D32, D33 | 8 | 1N5819W | D_SOD-123 |  | 1N5819W |  | smt |  |  |  | 1N5819W | Diotec Semiconductor | https://www.mouser.co.id/ProductDetail/Diotec-Semiconductor/1N4148W?qs=OlC7AqGiEDmsbkbAeXQtXg%3D%3D
D14 | 1 | SS14 | D_SMA |  | SS14 |  | smt |  | C2480
D15 | 1 | SMBJ40A | D_SMA |  | SMBJ40A |  | smt
D34 | 1 | BAT54C | SOT-23 |  |  |  | smt | dual schottky barrier diode, common cathode
F1 | 1 | 0.5A | Fuse_1206_3216Metric |  |  |  | smt | Resettable fuse, polymeric positive temperature coefficient, small symbol
F2 | 1 | 1206 | Fuse_1206_3216Metric |  |  |  | smt | Resettable fuse, polymeric positive temperature coefficient, small symbol
FB1 | 1 | Ferrite_Bead | L_0805_2012Metric |  |  |  | smt |  | C1015 | 0
IC1, IC2 | 2 | SN74LVC2G17DBVR | SOT95P280X145-6N |  | SN74LVC2G17DBVR |  | smt | DUAL SCHMITT-TRIGGER BUFFER | C10429 |  |  | Texas Instruments |  |  |  | 1.45 | 595-SN74LVC2G17DBVR | https://www.mouser.co.uk/ProductDetail/Texas-Instruments/SN74LVC2G17DBVR?qs=X1HXWTtiZ0RnstCufGEJxQ%3D%3D
J1 | 1 | Conn_01x04 | JST_XH_S4B-XH-A-1_1x04_P2.50mm_Horizontal |  |  |  | tht | Generic connector, single row, 01x04, script generated (kicad-library-utils/schlib/autogen/connector/)
J2 | 1 | STLink | PinHeader_1x04_P2.54mm_Vertical |  |  |  | tht | Generic connector, single row, 01x04, script generated (kicad-library-utils/schlib/autogen/connector/)
J3 | 1 | TYPE-C 16PIN 2MD(073) | USB_C_Receptacle_GCT_USB4105-xx-A_16P_TopMnt_Horizontal |  | TYPE-C 16PIN 2MD(073) |  | tht | USB 2.0-only Type-C Receptacle connector | C2765186 |  |  |  |  |  |  |  |  |  | SHOU HAN
J4, J7, J8 | 3 | Conn_01x02 | PinHeader_1x02_P2.54mm_Vertical |  |  |  | tht | Generic connector, single row, 01x02, script generated (kicad-library-utils/schlib/autogen/connector/)
J5 | 1 | THD2528-11SD-GF | CUI_MSD-1-A |  | THD2528-11SD-GF |  | smt |  |  |  |  |  |  |  |  |  |  |  | THD | 1.0 | Manufacturer Recommendations | 2.00mm | CUI Devices | C283232
J6 | 1 | USB | PinHeader_2x02_P2.54mm_Vertical |  |  |  | tht | Generic connector, single row, 01x04, script generated (kicad-library-utils/schlib/autogen/connector/)
J9 | 1 | 1554458-2 | 15544582 |  | 1554458-2 |  | tht | 33POS,1.0X0.64,TAB HSG ASSY,SLD |  |  |  | TE Connectivity |  |  |  | 21.3 | N/A | https://www.mouser.co.uk/ProductDetail/TE-Connectivity/1554458-2?qs=wnTfsH77Xs6dOQTyCnTAMQ%3D%3D
JP1 | 1 | Ignition Voltage | PinHeader_1x03_P2.54mm_Vertical |  | M20-9990345 |  | tht |  |  |  | 952-2263-ND | Harwin Inc | https://www.digikey.com.au/products/en?keywords=M20-9990345
JP2, JP7 | 2 | PULLUP | SolderJumper-2_P1.3mm_Open_RoundedPad1.0x1.5mm |  | DNP |  | tht
JP8, JP9 | 2 | HALL_VR | SolderJumper-3_P1.3mm_Open_RoundedPad1.0x1.5mm |  | DNP |  | tht
LED1, LED2, LED3 | 3 | RED | LED_0603_1608Metric |  | SML-310LTT86 |  | smt |  | C2286
P1 | 1 | Dual VR C | DIP-8_W7.62mm_Socket |  | DNP |  | tht
Q1, Q11, Q2, Q3, Q4, Q6 | 6 | Q_NMOS_GDS | TO-252-3_TabPin2 |  | STP62NS04Z |  | smt |  |  |  | 497-5896-5-ND | ST
Q10, Q5, Q7, Q8, Q9 | 5 | AO3400A | SOT-23 |  | AO3400A |  | smt | 30V Vds, 5.7A Id, N-Channel MOSFET, SOT-23 | C20917 |  |  |  |  |  | C344010
Q12, Q13 | 2 | ISL9V3040D3S | TO-263-2 |  |  |  | smt |  | C462128
R1, R102, R15, R16, R2, R43 | 6 | 100k | R_0603_1608Metric |  | MBA02040C1003FCT00 |  | smt |  | C25803 |  | BC3240CT-ND | Vishay | https://www.digikey.com.au/product-detail/en/vishay-beyschlag-draloric-bc-components/MBA02040C1003FCT00/BC3240CT-ND/6138743
R10, R23, R24, R9 | 4 | 2.4k | R_0603_1608Metric |  | MBA02040C2401FC100 |  | smt |  | C22940 |  | BC3483CT-ND | Vishay | https://www.digikey.com.au/product-detail/en/vishay-beyschlag-draloric-bc-components/MBA02040C2401FC100/BC3483CT-ND/7350913
R103, R17, R18, R19, R20, R29, R47, R5, R6 | 9 | 1k | R_0603_1608Metric |  | MBA02040C1001FRP00 |  | smt |  | C21190 |  | BC1.00KXCT-ND | Vishay
R11, R12 | 2 | 470r | R_0603_1608Metric |  | MBA02040C2401FC100 |  | smt |  |  |  | BC3483CT-ND | Vishay | https://www.digikey.com.au/product-detail/en/vishay-beyschlag-draloric-bc-components/MBA02040C2401FC100/BC3483CT-ND/7350913
R13, R28, R44, R65, R66, R71, R72, R73, R74 | 9 | 470 | R_0603_1608Metric |  |  |  | smt | Resistor
R14, R67, R68, R69, R70, R75, R76, R77, R78 | 9 | 910 | R_0603_1608Metric |  |  |  | smt | Resistor | C140066
R21, R22 | 2 | 470R | R_0603_1608Metric |  | MBA02040C1001FRP00 |  | smt |  |  |  | BC1.00KXCT-ND | Vishay
R25, R26, R41, R42, R50, R51, R54, R55 | 8 | 2k7 | R_0603_1608Metric |  | MBA02040C1001FRP00 |  | smt |  | C22962 |  | BC1.00KXCT-ND | Vishay
R27, R64 | 2 | 10K | R_0603_1608Metric |  |  |  | smt | Resistor
R3, R4 | 2 | 10k | R_0603_1608Metric |  | MBA02040C1003FCT00 |  | smt |  |  |  | BC3240CT-ND | Vishay | https://www.digikey.com.au/product-detail/en/vishay-beyschlag-draloric-bc-components/MBA02040C1003FCT00/BC3240CT-ND/6138743
R30 | 1 | 3.9k | R_0603_1608Metric |  | MBA02040C3901FCT00 |  | smt |  | C23018 |  | BC3272CT-ND | Vishay | https://www.digikey.com.au/product-detail/en/vishay-beyschlag-draloric-bc-components/MBA02040C3901FCT00/BC3272CT-ND/6138775
R31, R32, R34, R38, R39, R40, R48, R92 | 8 | 470R | R_0603_1608Metric |  | MBA02040C4700FRP00 |  | smt |  | C23179 |  | BC3516CT-ND | Vishay | https://www.digikey.com.au/product-detail/en/vishay-beyschlag-draloric-bc-components/MBA02040C4700FRP00/BC3516CT-ND/7350946
R33 | 1 | 10k | R_0603_1608Metric |  | MBA02040C2401FC100 |  | smt |  | C25804 |  | BC3483CT-ND | Vishay | https://www.digikey.com.au/product-detail/en/vishay-beyschlag-draloric-bc-components/MBA02040C2401FC100/BC3483CT-ND/7350913
R35, R36, R91 | 3 | 2.7k | R_0603_1608Metric |  | MBA02040C2491FRP00 |  | smt |  |  |  | BC2.49KXCT-ND | Vishay | https://www.digikey.com.au/product-detail/en/vishay-beyschlag-draloric-bc-components/MBA02040C2491FRP00/BC2-49KXCT-ND/336807
R37, R8 | 2 | 1k | R_0603_1608Metric |  |  |  | smt |  | C11702 | 0
R45, R59, R62, R63, R84, R85, R90, R94 | 8 | 10k | R_0603_1608Metric |  |  |  | smt | [R90,R94]Resistor, small symbol; [R84,R85]Resistor |  |  |  |  |  |  | [R45]C21190; [R59,R62,R63,R90,R94]C25804
R46, R60, R61, R89, R93 | 5 | 100R | R_0603_1608Metric |  |  |  | smt | Resistor, small symbol | C22775 |  |  |  |  |  | C22775
R52, R53 | 2 | 15R | R_2512_6332Metric |  | MBA02040C2401FC100 |  | smt |  |  |  | BC3483CT-ND | Vishay | https://www.digikey.com.au/product-detail/en/vishay-beyschlag-draloric-bc-components/MBA02040C2401FC100/BC3483CT-ND/7350913
R58 | 1 | 1M | R_0603_1608Metric |  |  |  | smt | Resistor | C22935
R7 | 1 | 120R | R_0603_1608Metric |  |  |  | smt | Resistor | C23162
R79, R80 | 2 | 5.1K | R_0603_1608Metric |  |  |  | smt | Resistor | C23186
R81, R82 | 2 | 22R | R_0603_1608Metric |  |  |  | smt | Resistor | C23345
R83 | 1 | 4.7K | R_0603_1608Metric |  |  |  | smt | Resistor | C23162
R86 | 1 | 2k7 | R_0603_1608Metric |  | RK73B1JTTD272J |  | smt |  | C13167
R87, R88 | 2 | 470r | R_0603_1608Metric |  | RK73H2ATTD4700F |  | smt | Resistor
SW1, SW2 | 2 | SW_Push | SW_SPST_CK_RS282G05A3 |  | TSA363G25-250B |  | smt | Push button switch, generic, two pins | C354943 |  |  |  |  |  |  |  |  |  |  |  |  |  |  | C354943
U1 | 1 | STM32F407VGTx | LQFP-100_14x14mm_P0.5mm |  | STM32F407VGT6 |  | smt | STMicroelectronics Arm Cortex-M4 MCU, 1024KB flash, 192KB RAM, 168 MHz, 1.8-3.6V, 82 GPIO, LQFP100 | C12345 |  |  |  |  |  |  |  |  |  | STMicroelectronics
U2 | 1 | TC4424AVOA | SOIC127P599X175-8N |  | TC4424AVOA |  | smt |  | C44150 |  |  | Microchip | https://www.digikey.com.au/product-detail/en/microchip-technology/TC4424AVPA/TC4424AVPA-ND/1098910
U3 | 1 | AMS1117-3.3 | SOT-223-3_TabPin2 |  |  |  | smt | 1A Low Dropout regulator, positive, 3.3V fixed output, SOT-223 | C6186
U4 | 1 | SRV05-4 | SOT-23-6 |  |  |  | smt
U5, U6 | 2 | MCP6004 | SOIC127P600X175-14N |  |  |  | smt | 1MHz, Low-Power Op Amp, DIP-14/SOIC-14/TSSOP-14
U7 | 1 | TJA1051T/3/1J | SOIC-8_3.9x4.9mm_P1.27mm |  |  |  | smt | High-Speed CAN Transceiver, 1Mbps, 5V supply, SOIC-8 | C38695
U8 | 1 | LM2940S-5.0 | TO-263-3_TabPin2 |  | NCV7805BTG |  | smt |  |  |  | NCV7805BTGOS-ND | ON Semi | https://www.digikey.com.au/product-detail/en/on-semiconductor/NCV7805BTG/NCV7805BTGOS-ND/921437
U9 | 1 | LPS25HB | ST_HLGA-10_2.5x2.5mm_P0.6mm_LayoutBorder3x2y |  |  |  | smt |  | C94049 | 1
Y1 | 1 | 8Mhz | Crystal_SMD_5032-2Pin_5.0x3.2mm |  | X50328MSB2GI |  | smt | Two pin crystal, small symbol | C115962 |  |  |  |  |  |  |  |  |  | YXC Crystal Oscillators
Y2 | 1 | 32.768KHz | Crystal_SMD_3215-2Pin_3.2x1.5mm |  | Q13FC13500004 |  | smt | Two pin crystal, small symbol | C32346 |  |  |  |  |  |  |  |  |  | Seiko Epson

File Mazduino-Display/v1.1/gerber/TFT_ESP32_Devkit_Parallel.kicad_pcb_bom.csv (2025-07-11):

Designator | Quantity | Value | Footprint | Package | MPN | DNP | Mount_Type | Description
C1, C13 | 2 | 220uF | C_Elec_8x10.2 |  |  |  | smt | Polarized capacitor, small symbol
C10, C11, C4, C6, C8 | 5 | 0.1uF/100nF | C_0805_2012Metric |  |  |  | smt | Unpolarized capacitor, small symbol
C12, C3 | 2 | 22uF | CP_Elec_5x5.4 |  |  |  | smt | Polarized capacitor, small symbol
C2 | 1 | 100nF | C_0805_2012Metric |  |  |  | smt | Unpolarized capacitor, small symbol
C5, C7 | 2 | 22uF | C_0805_2012Metric |  |  |  | smt | Unpolarized capacitor, small symbol
C9 | 1 | 100nF | C_0603_1608Metric |  |  |  | smt | Unpolarized capacitor
D2 | 1 | SS14 | D_SMA |  |  |  | smt | 60V 2A Schottky Diode, SMA
D3 | 1 | SP0503BAHT | SOT-143 |  |  |  | smt | TVS Diode Array, 5.5V Standoff, 3 Channels, SOT-143 package
D4, D5 | 2 | SS36 | D_SMA |  |  |  | smt | 60V 3A Schottky Diode, SMA
J1 | 1 | Conn_01x02_Pin | JST_XH_B2B-XH-A_1x02_P2.50mm_Vertical |  |  |  | tht | Generic connector, single row, 01x02, script generated
J2 | 1 | JST 4P | JST_XH_B4B-XH-A_1x04_P2.50mm_Vertical |  |  |  | tht | Generic connector, single row, 01x04, script generated
J3 | 1 | TFT SPI | PinSocket_1x14_P2.54mm_Vertical |  |  |  | tht | Generic connector, single row, 01x14, script generated
J5 | 1 | USB_C_Receptacle_USB2.0 | USB_C_Receptacle_GCT_USB4105-xx-A_16P_TopMnt_Horizontal |  |  |  | smt | USB 2.0-only Type-C Receptacle connector
J6, J7 | 2 | TFT SD | PinSocket_1x04_P2.54mm_Vertical |  |  |  | tht | Generic connector, single row, 01x04, script generated
JP1 | 1 | Jumper_2_Open | PinHeader_1x02_P2.54mm_Vertical |  |  |  | tht | Jumper, 2-pole, open
L1 | 1 | 330uH | L_10.4x10.4_H4.8 |  |  |  | smt | Inductor
LED1, LED4 | 2 | LED | LED_0805_2012Metric |  |  |  | smt | Light emitting diode
LED2 | 1 | BLUE | LED_0805_2012Metric |  |  |  | smt | Light emitting diode
LED3 | 1 | GREEN | LED_0805_2012Metric |  |  |  | smt | Light emitting diode
Q1, Q2 | 2 | SS8050 | SOT-23 |  |  |  | smt | General Purpose NPN Transistor, 1.5A Ic, 25V Vce, SOT-23
R1, R10, R6, R9 | 4 | 10K | R_0805_2012Metric |  |  |  | smt | Resistor
R11 | 1 | 4.7K | R_0603_1608Metric |  |  |  | smt | Resistor
R12, R13, R17 | 3 | 5k1 | R_0805_2012Metric |  |  |  | smt | Resistor
R14 | 1 | 120R | R_0805_2012Metric |  |  |  | smt | Resistor
R15, R16 | 2 | 100R | R_0805_2012Metric |  |  |  | smt | Resistor
R18 | 1 | 560K | R_0805_2012Metric |  |  |  | smt | Resistor
R19 | 1 | 4.7K | R_0805_2012Metric |  |  |  | smt | Resistor
R2 | 1 | 22.1K | R_0805_2012Metric |  |  |  | smt | Resistor
R3 | 1 | 470R | R_0805_2012Metric |  |  |  | smt | Resistor
R4 | 1 | 47.5K | R_0805_2012Metric |  |  |  | smt | Resistor
R5 | 1 | 2K | R_0805_2012Metric |  |  |  | smt | Resistor
R7, R8 | 2 | 0R | R_0805_2012Metric |  |  |  | smt | Resistor
SW1, SW2 | 2 | SW_Push | SW_PUSH_6mm |  |  |  | tht | Push button switch, generic, two pins
U1 | 1 | AMS1117-3.3 | SOT-223-3_TabPin2 |  |  |  | smt | 1A Low Dropout regulator, positive, 3.3V fixed output, SOT-223
U3 | 1 | ESP32-WROOM-32D | ESP32-WROOM-32D |  |  |  | smt | RF Module, ESP32-D0WD SoC, Wi-Fi 802.11b/g/n, Bluetooth, BLE, 32-bit, 2.7-3.6V, onboard antenna, SMD
U4 | 1 | CP2102N-Axx-xQFN28 | QFN-28-1EP_5x5mm_P0.5mm_EP3.35x3.35mm |  |  |  | smt | USB to UART master bridge, QFN-28
U5 | 1 | MCP2551-I-SN | SOIC-8_3.9x4.9mm_P1.27mm |  |  |  | smt | High-Speed CAN Transceiver, 1Mbps, 5V supply, SOIC-8
U6 | 1 | ESP32-DevKitC | ESP32-DevKitC |  |  |  | tht | Development Kit
U7 | 1 | LM2596S-5 | TO-263-5_TabPin3 |  |  |  | smt | 5V 3A Step-Down Voltage Regulator, TO-263

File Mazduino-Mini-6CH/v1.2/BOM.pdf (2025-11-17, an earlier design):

Reference | Value | Footprint | Qty
C1,C2,C3,C4,C9,C10,C11,C15,C16,C18,C19,C20,C24,C30,C35,C36,C38,C39,C40,C41,C42,C44,C45,C46,C47,C49,C51 100nF | | Capacitor_SMD:C_0603_1608Metric | 27
C5,C6,C7,C12,C13,C14,C50,C52 | 220nF | Capacitor_SMD:C_0603_1608Metric | 8
C8 | 470pF | Capacitor_SMD:C_0603_1608Metric | 1
C17 | 47uF | Capacitor_SMD:CP_Elec_8x6.5 | 1
C21 | 47uF | Capacitor_SMD:CP_Elec_5x5.3 | 1
C22,C25,C29,C31,C33,C48 | 1uF | Capacitor_SMD:C_0603_1608Metric | 6
C23,C26 | 12pF | Capacitor_SMD:C_0603_1608Metric | 2
C27,C28 | 20pF | Capacitor_SMD:C_0603_1608Metric | 2
C32,C34,C53 | 2.2uF | Capacitor_SMD:C_0603_1608Metric | 3
C37 | 47uF | Capacitor_SMD:CP_Elec_5x5.4 | 1
C43 | 10uF | Capacitor_SMD:C_0603_1608Metric | 1
C54 | 22nF | Capacitor_SMD:C_0603_1608Metric | 1
D1,D2,D3,D4,D7,D8,D9,D10,D31,D33,D35,D36 | LED | LED_SMD:LED_0603_1608Metric | 12
D5,D6,D11,D12,D32,D34 | 1N4148WT | Diode_SMD:D_0603_1608Metric | 6
D13,D16,D25,D26,D29,D30,D40 | 1N5819W | Diode_SMD:D_SOD-123 | 7
D14 | SS16 | Diode_SMD:D_SMA | 1
D15 | D_TVS | Diode_SMD:D_SMA | 1
D17,D18,D19,D20,D21,D22,D23,D24,D27,D28,D37,D38,D39 BAT54S | | Package_TO_SOT_SMD:SOT-23 | 13
F1 | 0.5A | Fuse:Fuse_1206_3216Metric | 1
F2 | 0.5A | Fuse:Fuse_1206_3216Metric | 1
J2 | STLink | Connector_PinHeader_2.54mm:PinHeader_1x04_P2.54mm_Vertical | 1
J3 | USB_C_Receptacle_USB2.0 | Connector_USB:USB_C_Receptacle_GCT_USB4105-xx-A_16P_TopMnt_Horizontal | 1
J5 | MSD-1-A | MSD_1_A:CUI_MSD-1-A | 1
J6,J7 | Conn_01x02 | Connector_PinHeader_2.54mm:PinHeader_1x02_P2.54mm_Vertical | 2
J9 | Yamaha 48p | S48BZROK2AR | 1
JP1 | Ignition Voltage | Jumper:SolderJumper-3_P1.3mm_Open_RoundedPad1.0x1.5mm | 1
JP2,JP3 | HALL_VR | Jumper:SolderJumper-3_P1.3mm_Open_RoundedPad1.0x1.5mm | 2
JP4,JP5 | PULLUP | Jumper:SolderJumper-2_P1.3mm_Open_RoundedPad1.0x1.5mm | 2
LED1,LED2,LED3 | RED | LED_SMD:LED_0603_1608Metric | 3
P1 | DRV8825 | shield_footprint:DRV8825 | 1
P2 | Dual VR C | Package_DIP:DIP-8_W7.62mm_Socket | 1
Q1,Q2,Q3,Q4,Q6,Q10,Q11,Q12 | BSP78/NCV8405A/NCV8406A | Package_TO_SOT_SMD:SOT-223-3_TabPin2 | 8
Q5,Q7,Q8,Q9,Q13 | AO3400A | Package_TO_SOT_SMD:SOT-23 | 5
Q14 | BC817 | Package_TO_SOT_SMD:SOT-23 | 1
R1,R2,R15,R16,R43,R91,R93,R96 | 100k | Resistor_SMD:R_0603_1608Metric | 8
R3,R4,R19,R20,R27,R33,R45,R59,R62,R63,R64,R84,R85,R90,R99,R100,R113,R117,R118 10K | | Resistor_SMD:R_0603_1608Metric | 19
R5,R6,R17,R18,R29,R37,R41,R42,R47,R49,R92,R94,R97,R107 1k | | Resistor_SMD:R_0603_1608Metric | 14
R7,R8,R21,R22,R101,R102 | 0R | Resistor_SMD:R_0603_1608Metric | 6
R9,R10,R23,R24,R95,R98 | 2.4k | Resistor_SMD:R_0603_1608Metric | 6
R11,R12,R13,R25,R26,R28,R31,R32,R34,R38,R39,R40,R44,R48,R65,R66,R71,R72,R73,R74,R87,R88,R103,R104,R109,R110 470R | | Resistor_SMD:R_0603_1608Metric | 26
R14,R67,R68,R69,R70,R75,R76,R77,R78 | 910R | Resistor_SMD:R_0603_1608Metric | 9
R30 | 3.9k | Resistor_SMD:R_0603_1608Metric | 1
R35,R36 | 2.49k | Resistor_SMD:R_0603_1608Metric | 2
R46,R60,R61,R89,R112 | 100R | Resistor_SMD:R_0603_1608Metric | 5
R50,R51,R57 | 220R | Resistor_SMD:R_0603_1608Metric | 3
R52,R53,R54,R55,R105,R106 | 15R 2W | Resistor_SMD:R_2512_6332Metric | 6
R56,R86,R108 | 2k7 | Resistor_SMD:R_0603_1608Metric | 3
R58 | 1M | Resistor_SMD:R_0603_1608Metric | 1
R79,R80 | 5.1K | Resistor_SMD:R_0603_1608Metric | 2
R81,R82,R111 | 22R | Resistor_SMD:R_0603_1608Metric | 3
R83 | 4.7K | Resistor_SMD:R_0603_1608Metric | 1
R114,R116 | 68K | Resistor_SMD:R_0603_1608Metric | 2
R115 | 5.1R | Resistor_SMD:R_0603_1608Metric | 1
SW1,SW2 | SW_Push | Button_Switch_SMD:SW_SPST_CK_RS282G05A3 | 2
TP1,TP2 | TestPoint | TestPoint:TestPoint_Pad_D1.0mm | 2
U1 | STM32F407VGTx | Package_QFP:LQFP-100_14x14mm_P0.5mm | 1
U2,U4,U10 | TC4424A | TC4424AVOA:SOIC127P599X175-8N | 3
U3 | AMS1117-3.3 | Package_TO_SOT_SMD:SOT-223-3_TabPin2 | 1
U5,U6 | MCP6004 | MCP6004T_I_SL:SOIC127P600X175-14N | 2
U7 | MCP2551-I-SN | Package_SO:SOIC-8_3.9x4.9mm_P1.27mm | 1
U8 | LM2940S-5.0 | Package_TO_SOT_SMD:TO-263-3_TabPin2 | 1
U9 | USBLC6-2SC6 | Package_TO_SOT_SMD:SOT-23-6 | 1
Y1 | 8Mhz | Crystal:Crystal_SMD_5032-2Pin_5.0x3.2mm | 1
Y2 | 32.768KHz | Crystal:Crystal_SMD_3215-2Pin_3.2x1.5mm | 1

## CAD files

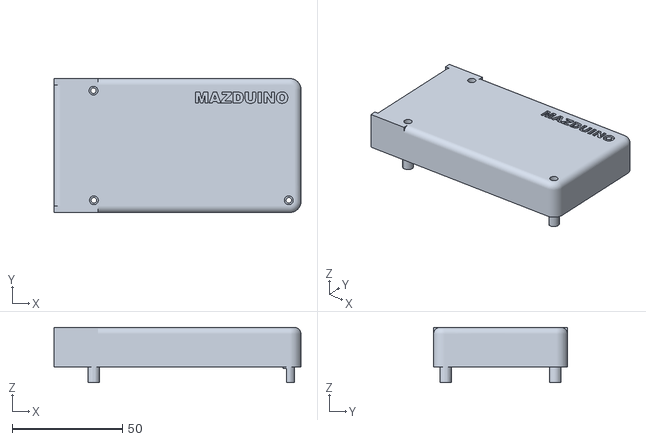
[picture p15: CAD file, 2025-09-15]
Mazduino-Compact/3D Case/COMPACT_TOP_V2.1.stl
112.0 x 60.8 x 25.0

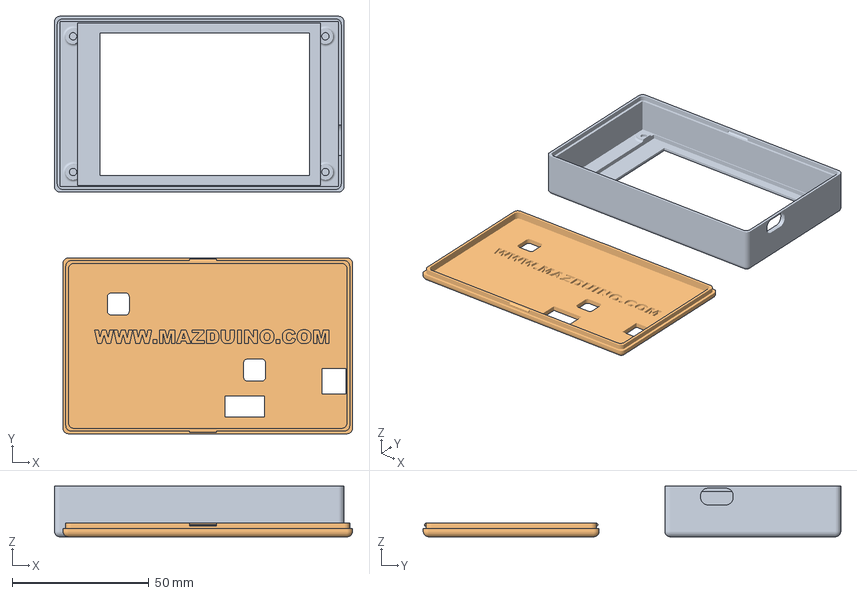
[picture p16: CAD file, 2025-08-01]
Mazduino-Display/3D Case/Display_case_TOP.3mf
108.9 x 152.6 x 18.5 mm
Display_case_TOP.stl
displau_case_BOTTOM.stl

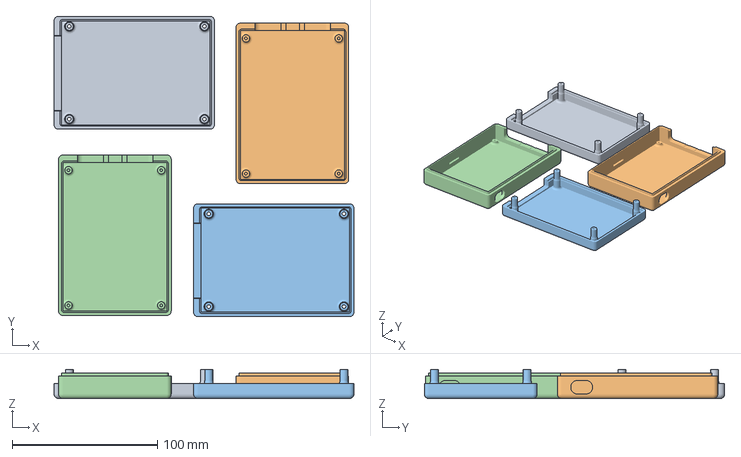
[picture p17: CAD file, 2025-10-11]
Mazduino-Mini-6CH/3D Case/Top_case_v2.3mf
206.4 x 206.5 x 20.0 mm
Top_case_v2.stl x 2
Bottom_case_v2.stl x 2

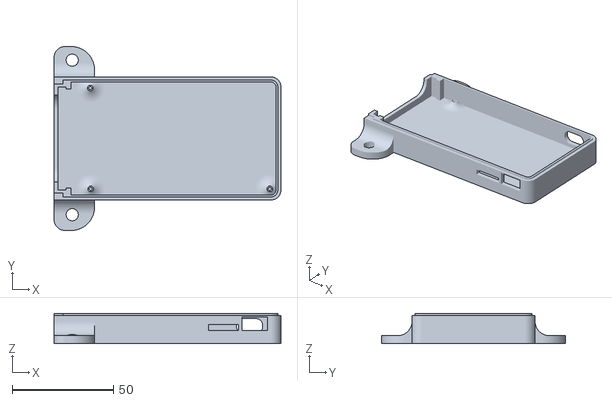
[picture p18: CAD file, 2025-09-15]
Mazduino-Compact/3D Case/COMPACT_BOTTOM_V2.1.stl
112.0 x 90.8 x 15.0

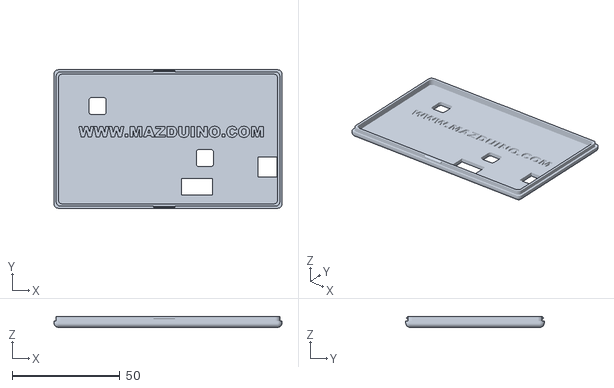
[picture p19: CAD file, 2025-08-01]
Mazduino-Display/3D Case/displau_case_BOTTOM.stl
105.8 x 64.3 x 5.00

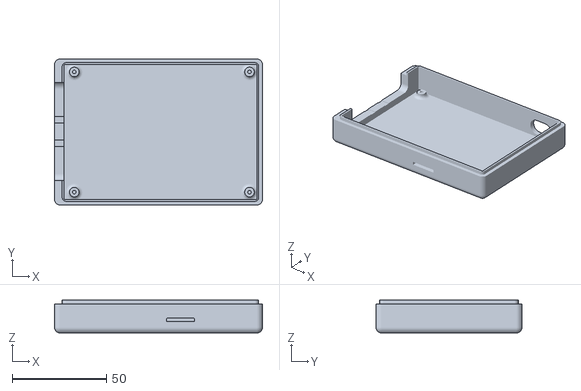
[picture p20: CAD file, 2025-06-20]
Mazduino-Mini-6CH/3D Case/Bottom_case_v2.stl
110.4 x 77.6 x 17.5

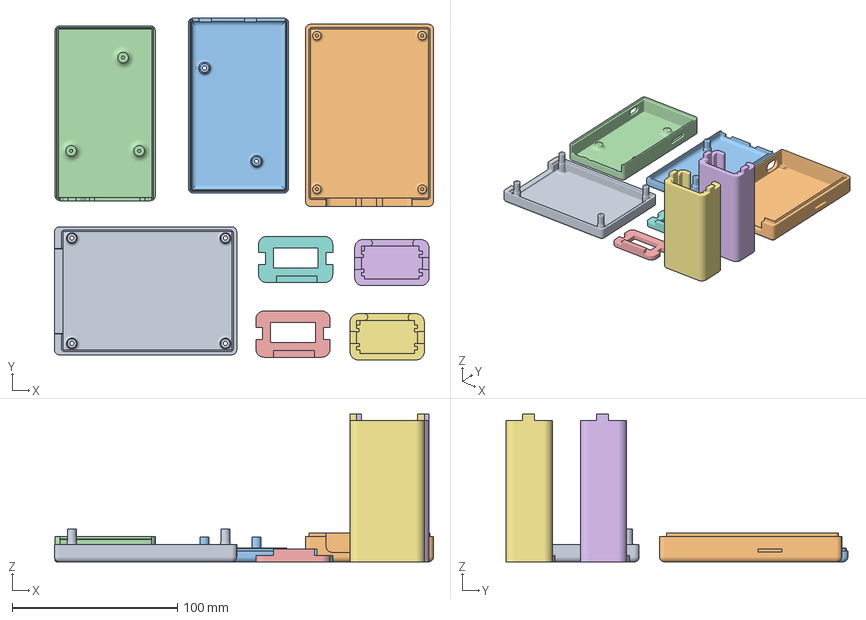
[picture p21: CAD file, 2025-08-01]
Mazduino-Compact/3D Case/Top_compact_v1.1.3mf
229.6 x 207.1 x 89.5 mm
Top_case_v2.stl
Bottom_case_v2.stl
compact_top_v1.2.stl
Compact_Bottom_v1.2.stl
SF2_Cap.stl x 2
14point7_body.stl x 2

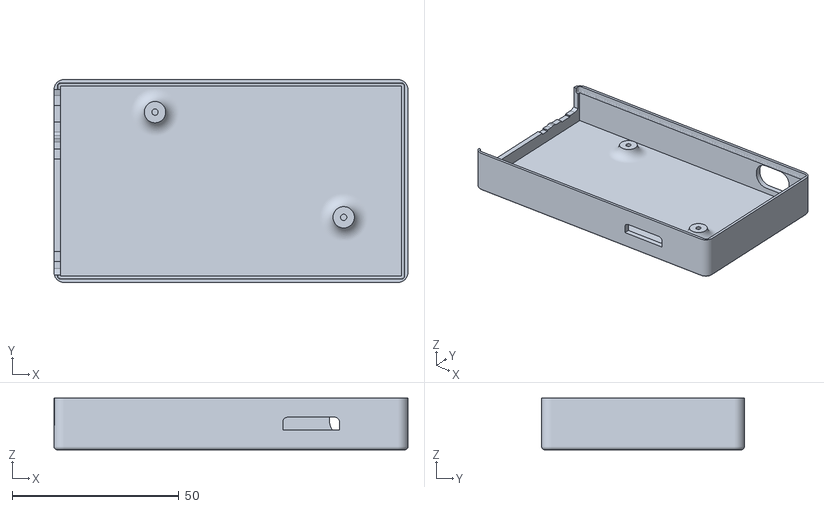
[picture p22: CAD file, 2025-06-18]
Mazduino-Compact/3D Case/Bottom_compact_v1.1.stl
106.0 x 60.8 x 15.5

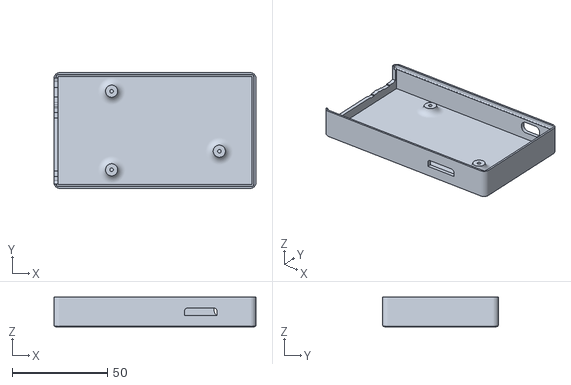
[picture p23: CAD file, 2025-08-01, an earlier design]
Mazduino-Compact/3D Case/Compact_Bottom_v1.2.stl
106.0 x 60.8 x 15.5

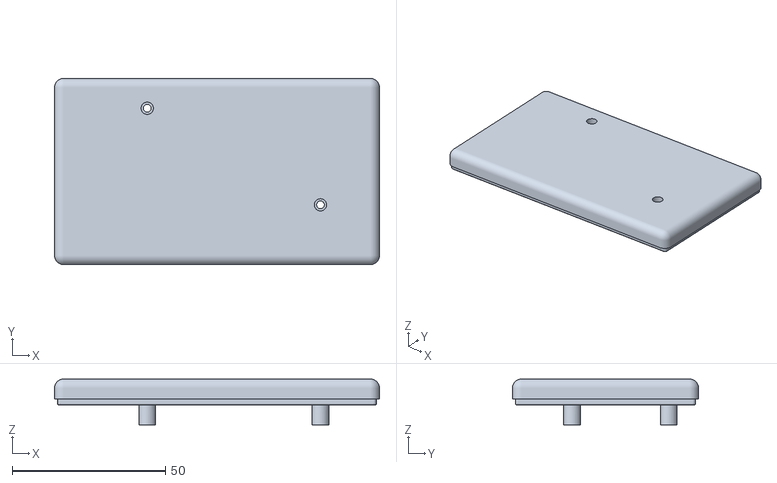
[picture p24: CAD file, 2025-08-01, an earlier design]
Mazduino-Compact/3D Case/compact_top_v1.2.stl
106.0 x 60.8 x 15.0

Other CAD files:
Mazduino-Compact/3D Case/Top_compact_v1.1.stl
Mazduino-Display/3D Case/Display_case_TOP.stl
Mazduino-Mini-6CH/3D Case/Top_case_v2.stl

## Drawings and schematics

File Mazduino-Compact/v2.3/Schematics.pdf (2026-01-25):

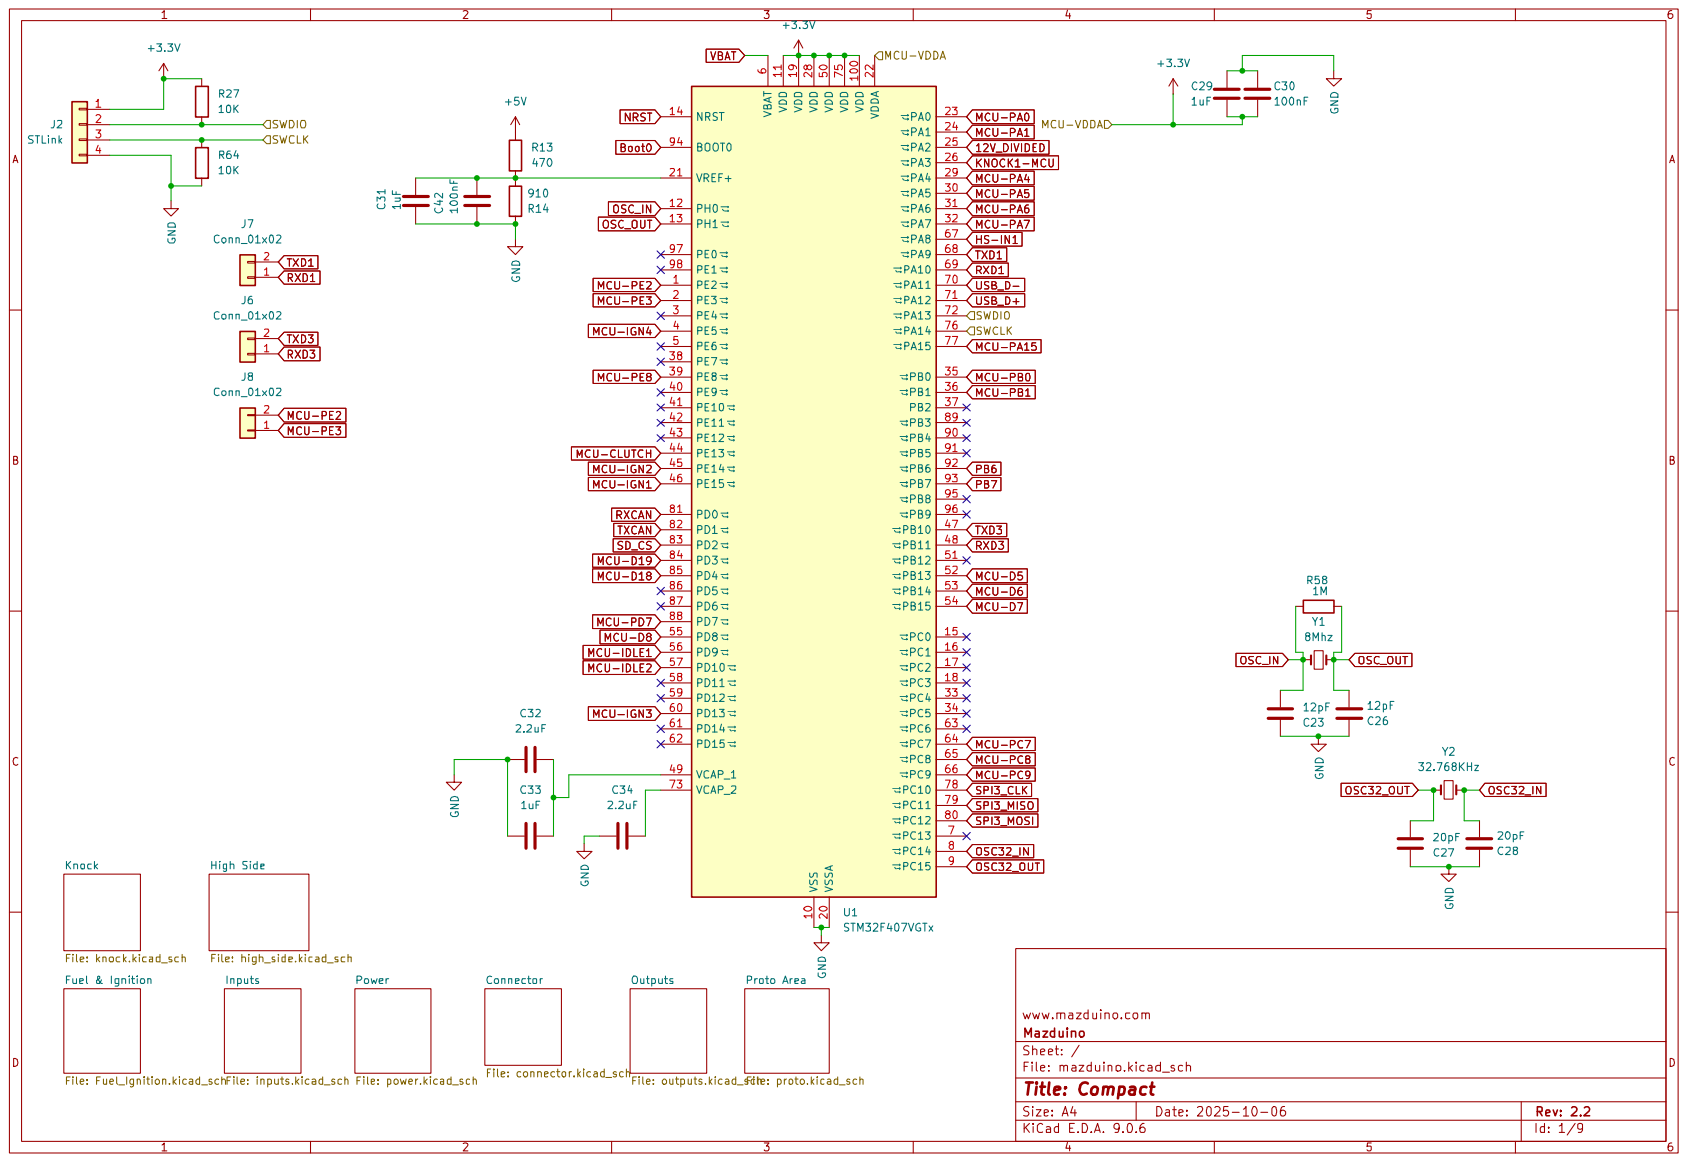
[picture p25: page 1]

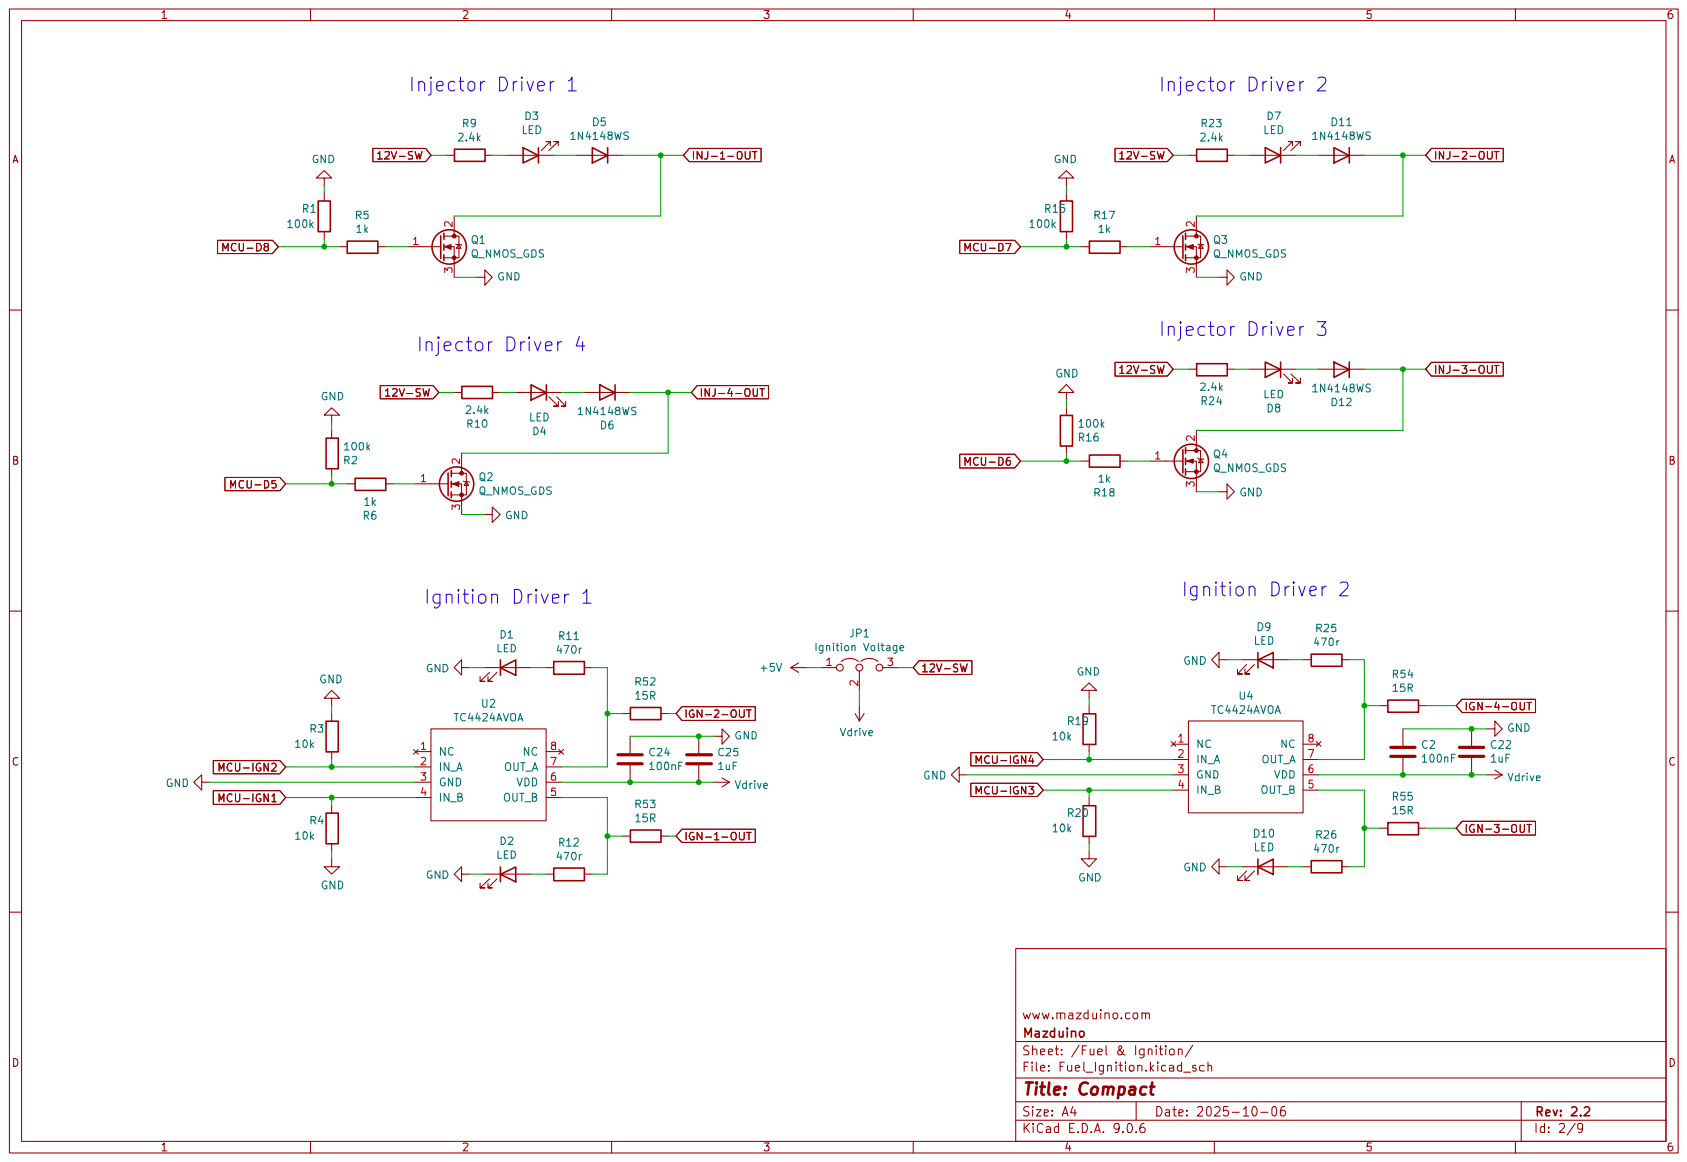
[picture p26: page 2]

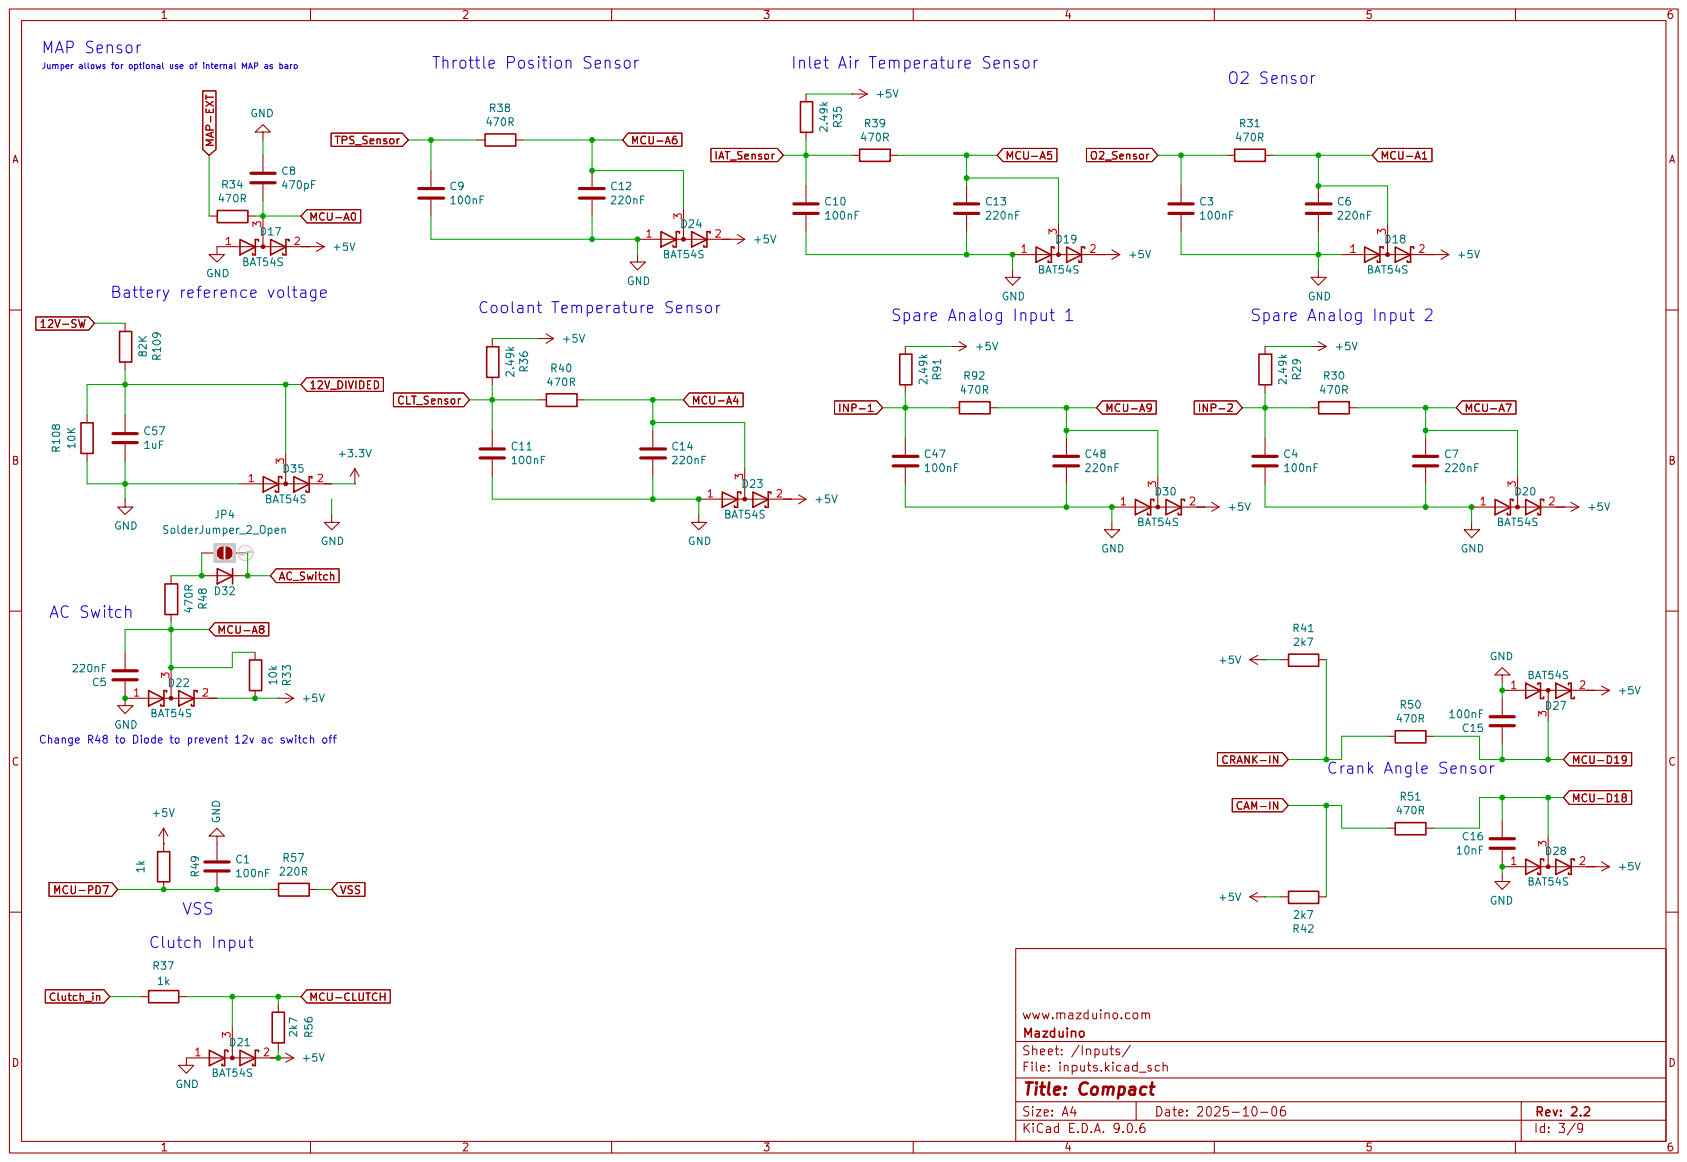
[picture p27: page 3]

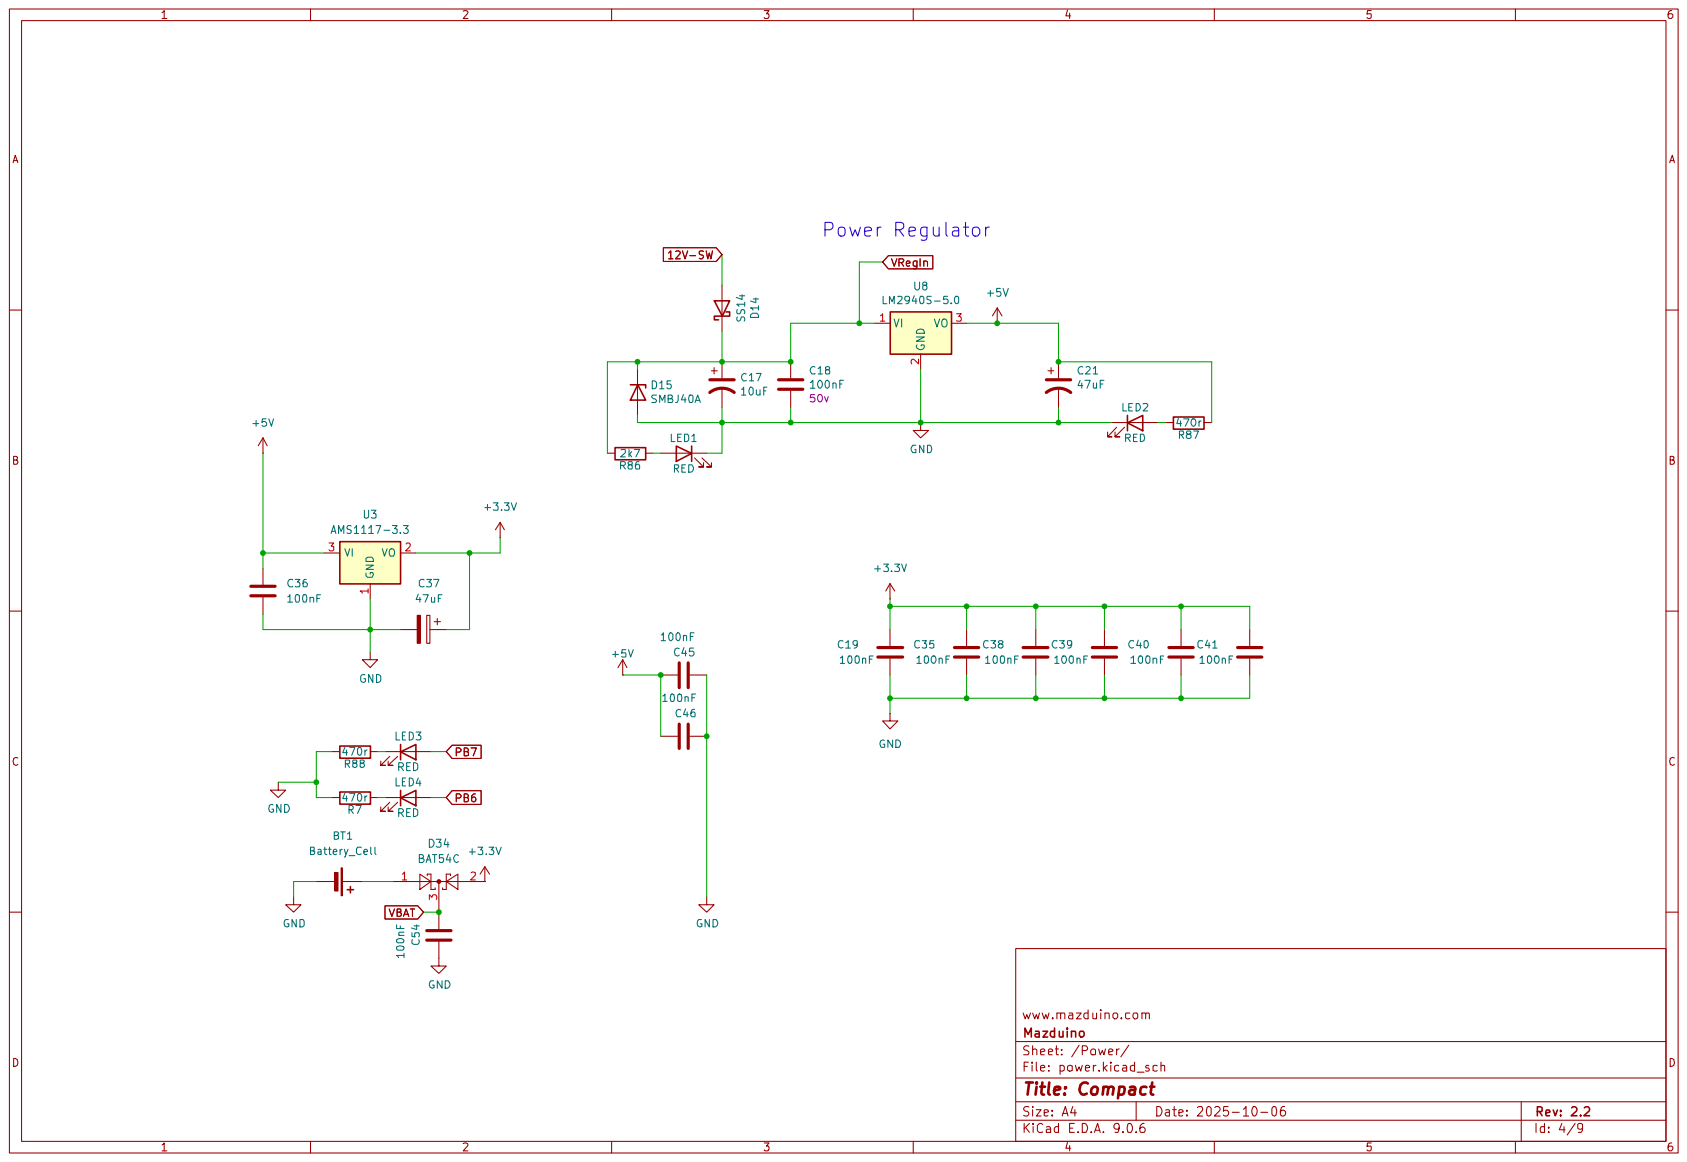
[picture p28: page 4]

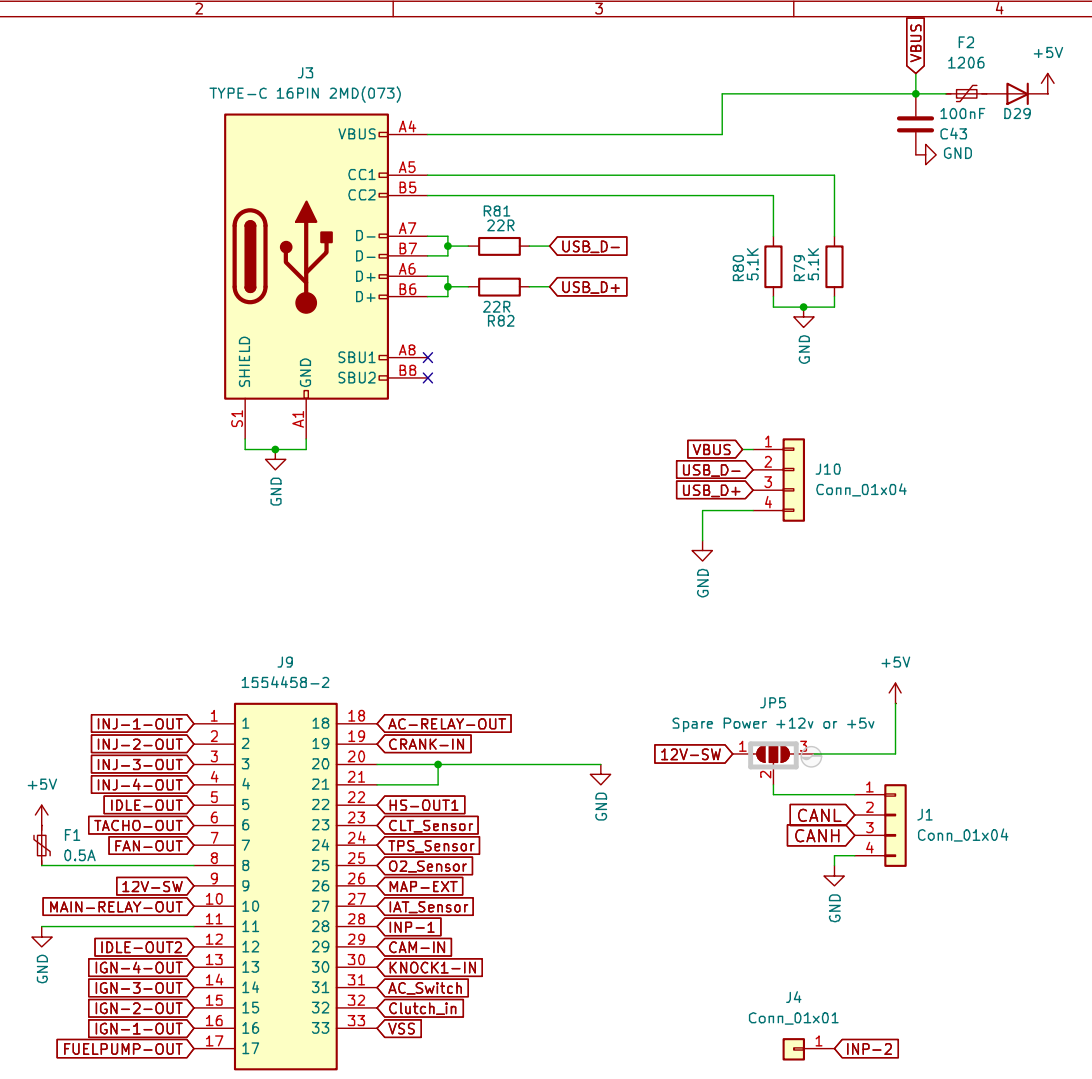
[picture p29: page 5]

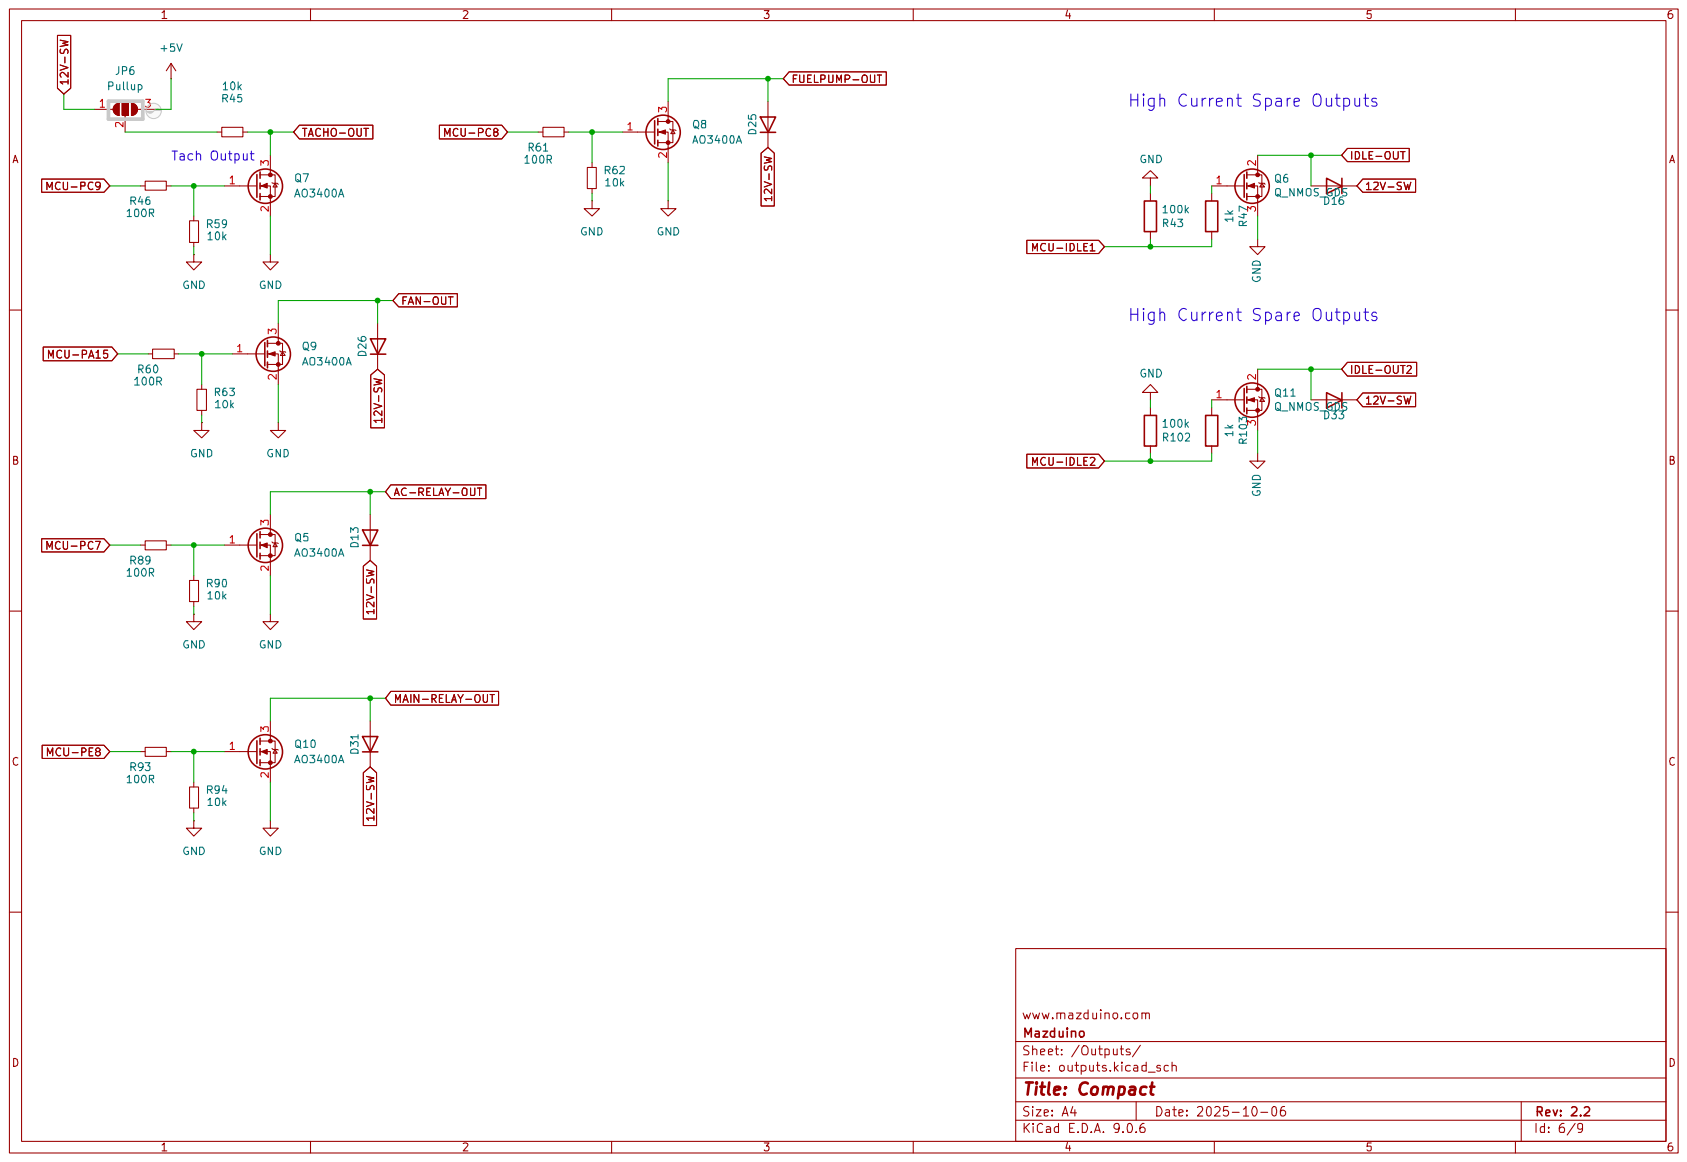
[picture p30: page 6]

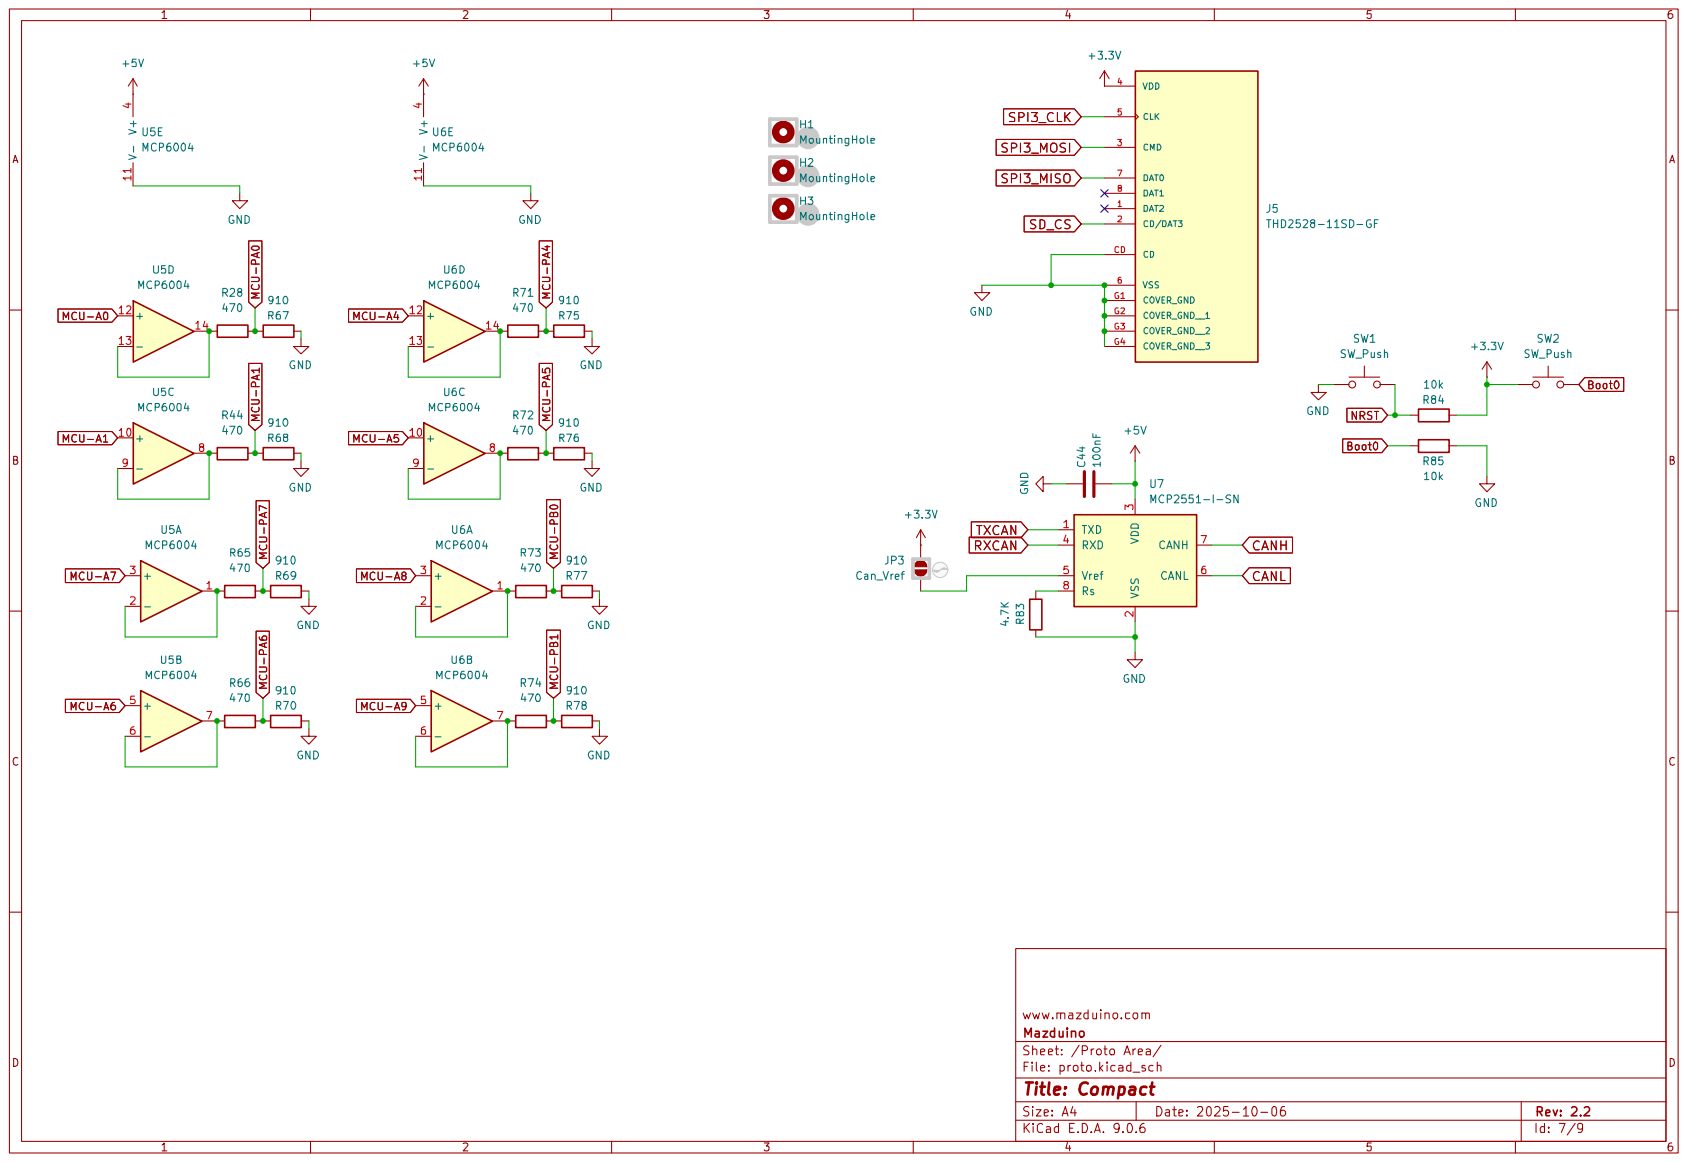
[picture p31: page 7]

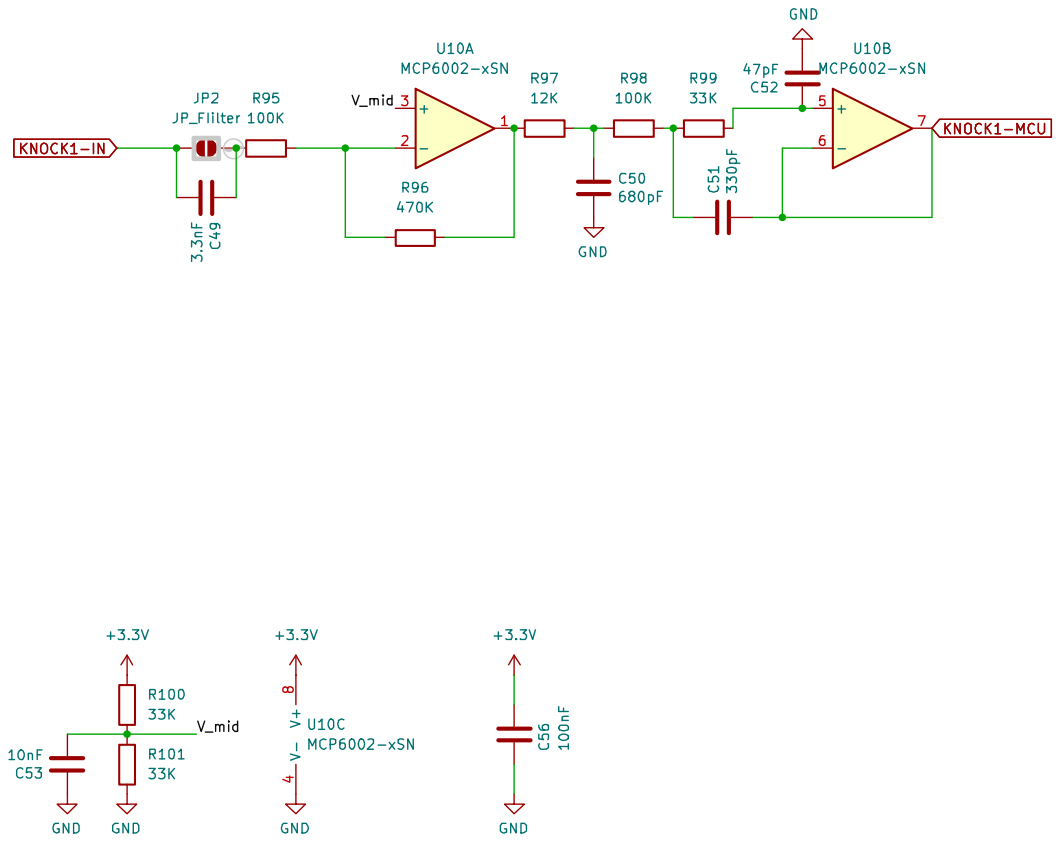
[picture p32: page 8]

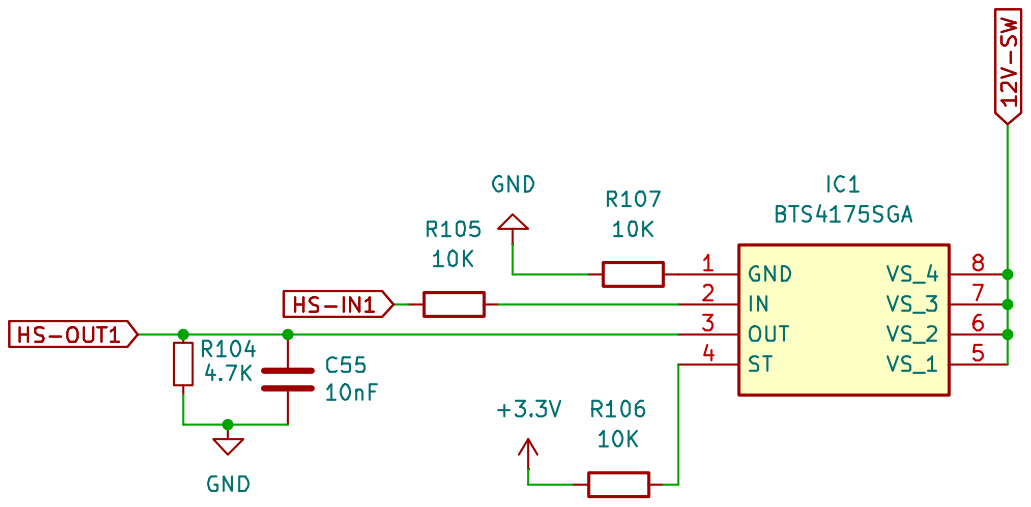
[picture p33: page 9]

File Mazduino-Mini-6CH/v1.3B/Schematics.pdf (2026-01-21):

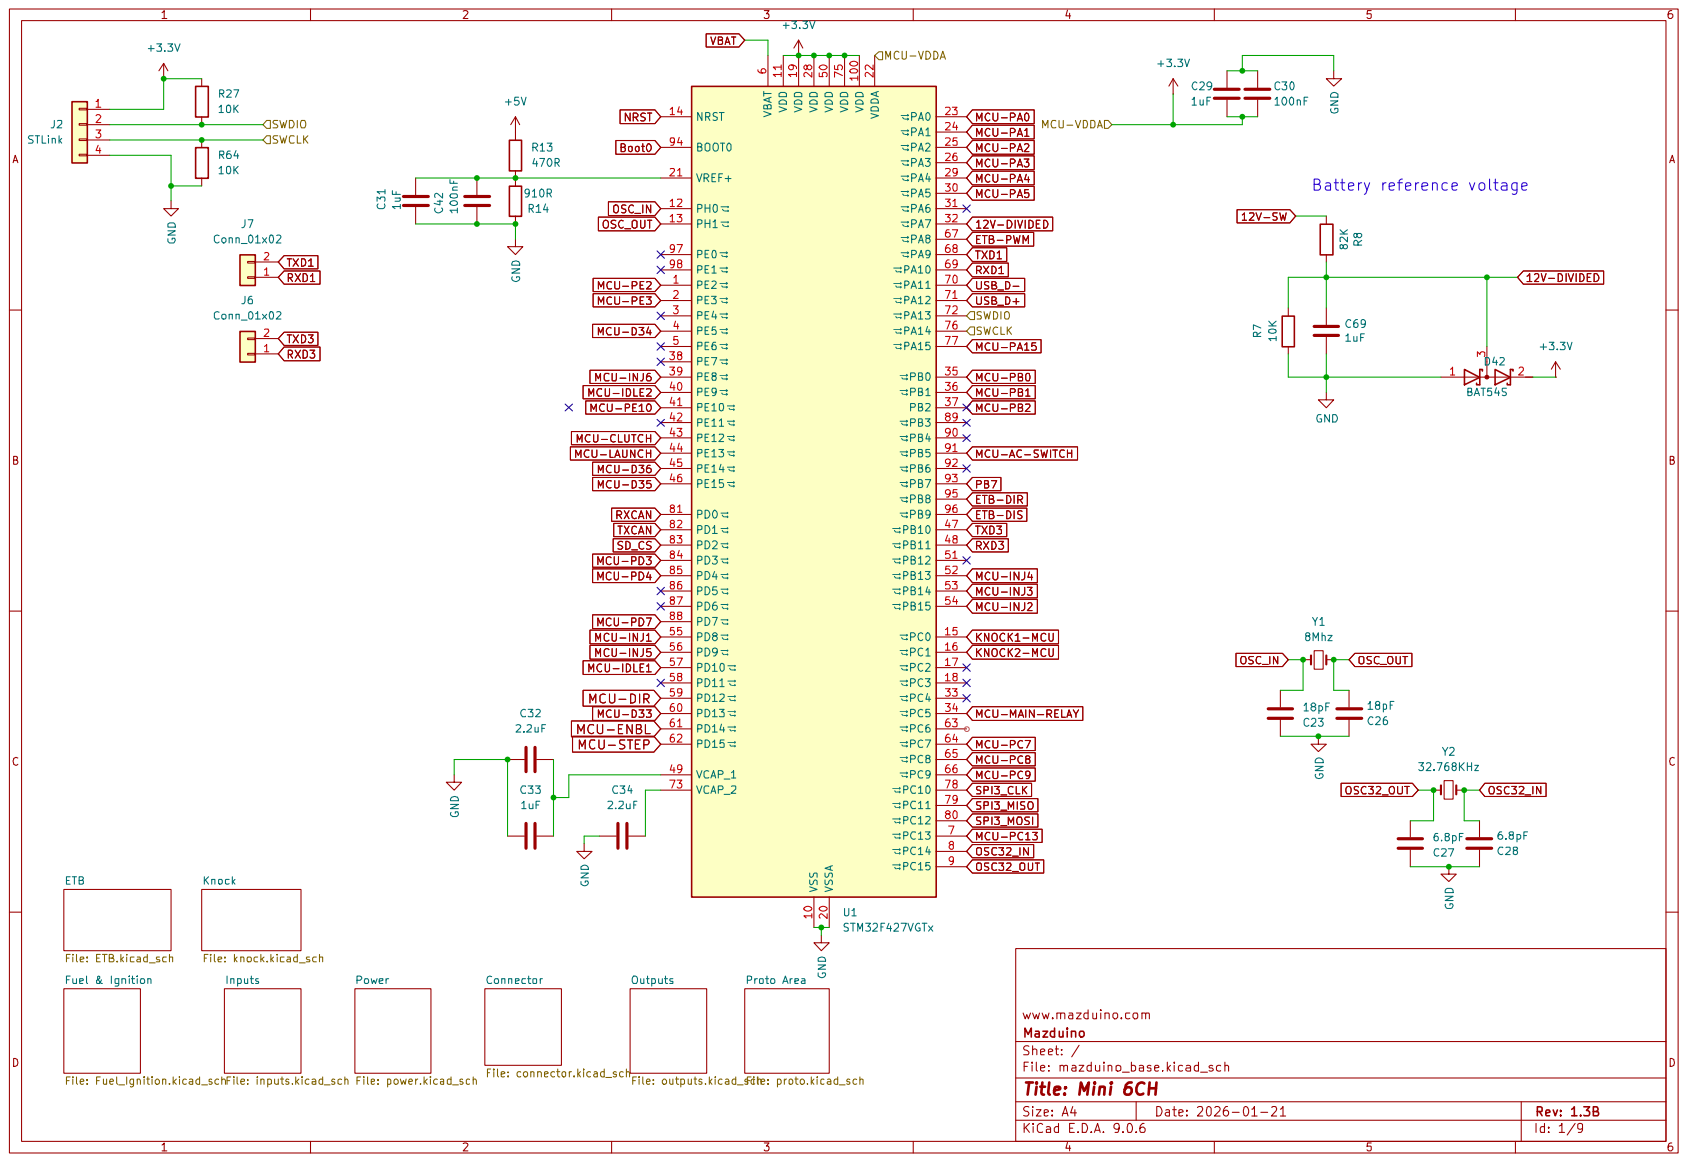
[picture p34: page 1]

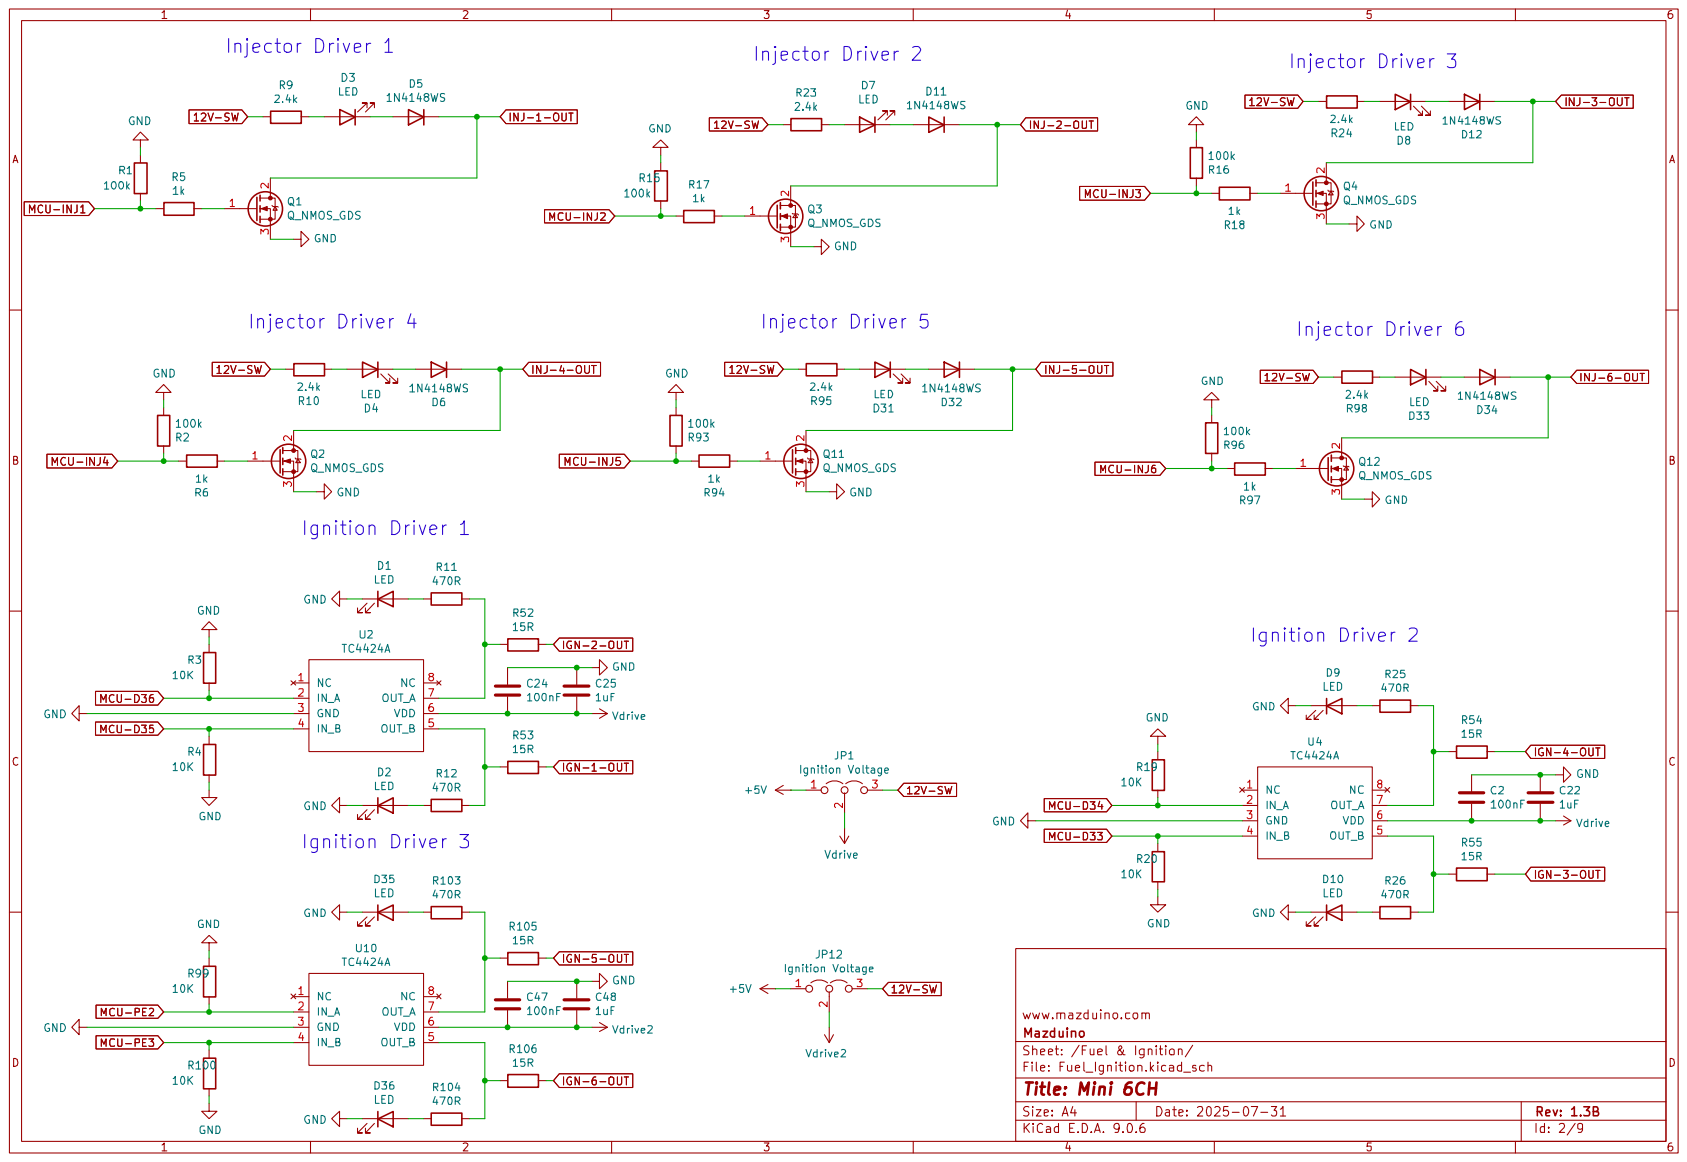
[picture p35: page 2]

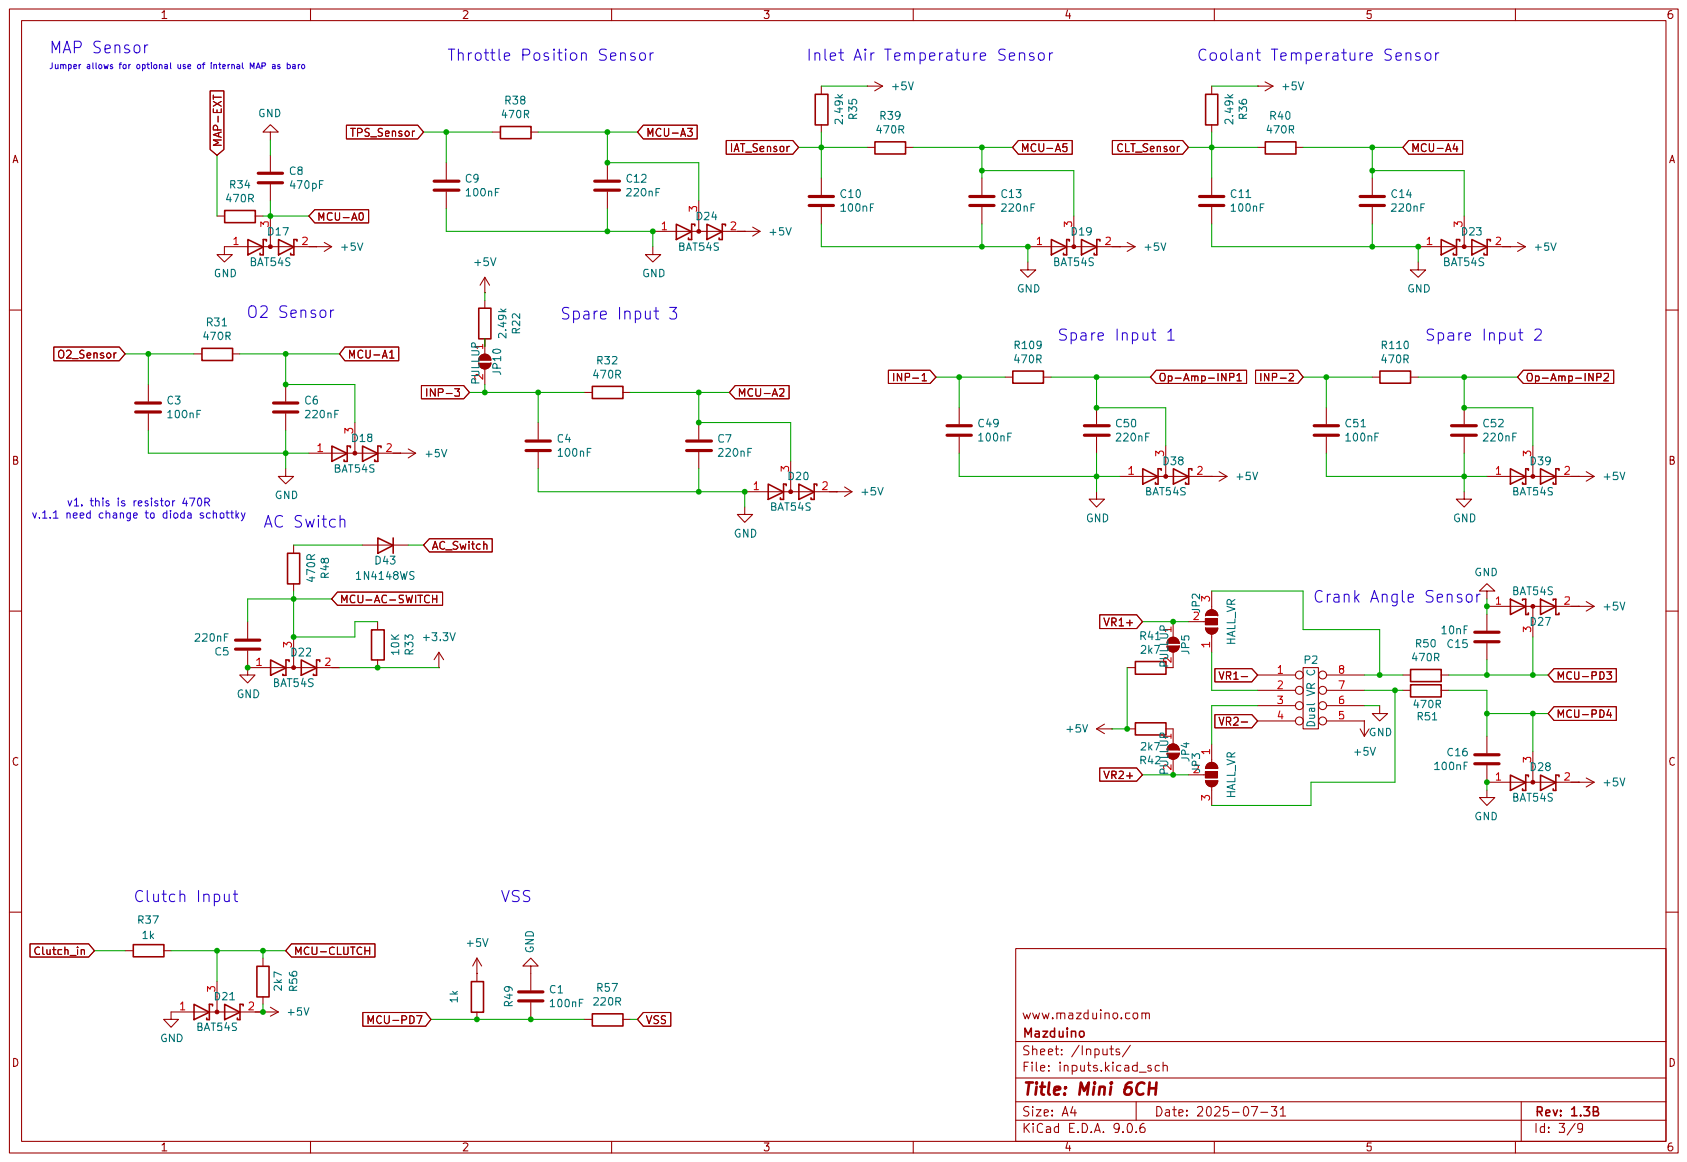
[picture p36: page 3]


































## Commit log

2024-12-16 clone from latest speeduino
    [Fuel_Ignition.kicad_sch, Fuel_Ignition.sch, connector.kicad_sch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]
2025-05-01 add document
    [Fuel_Ignition.kicad_sch, Fuel_Ignition.sch, connector.kicad_sch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]
2025-06-20 update mini 6ch
    [Bottom_case_v2.stl, Top_case_v2.stl, mazduino_base.kicad_pcb_bom.csv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]
2025-07-07 add compact v1.2
    [BOM.xlsx]
2025-09-15 add compact v2.0 schematics
    [mazduino.kicad_pcb_bom.csv, mazduino.kicad_pcb_positions.csv]
2025-09-15 add 3d case compact
    [COMPACT_BOTTOM_V2.1.stl, COMPACT_TOP_V2.1.stl]
2025-09-23 add v1.3
    [Top_case_v2.3mf, mazduino_base.kicad_pcb_bom.csv, mazduino_base.kicad_pcb_positions.csv]
2025-11-17 add BOM mini6ch v1.2
    [BOM.xlsx]
2025-11-21 update bom
2025-11-21 add mazduino lite
    [mazduino.kicad_pcb_bom.csv, mazduino.kicad_pcb_positions.csv]
2025-12-18 add revision v0.2 for mazduino lite. IGBT issue
    [mazduino.kicad_pcb_bom.csv, mazduino.kicad_pcb_positions.csv]
2026-01-21 add mini 6ch v1.3B
    [bom.csv, designators.csv, positions.csv]
2026-01-25 add v.2 compact
    [bom.csv, designators.csv, positions.csv]
